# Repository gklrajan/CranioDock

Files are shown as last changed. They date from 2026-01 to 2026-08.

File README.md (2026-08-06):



# CranioDock: Open-Source 3D-Printable Mounts for Brain Imaging with Visual and Auditory stimulation in Danionella

**CranioDock** is an open-source, modular 3D-printed mounting system designed for brain imaging in adult *Danionella* fish (and other similar animal models). This setup provides stable head-fixation, precise alignment with visual/ auditory stimuli, and easy integration with upright microscopes with water immersion or dry objectives that have sufficient working distance.

This repository contains all the necessary STL and STEP files to fabricate and assemble the mounting system, along with notes on assembly and experimental usage.

---

## Parts

| Part Name | File Path |
|---|---|
| Inner fish holder (common) | `models/fish-holder_v2-m.STL` |
| Outer chamber (for visual stimulation) | `models/visualStim_intubation-chamber_v2.STL` |
| Outer chamber (for auditory stimulation)  | `models/auditoryStim_outer-chamber_complete-setup_v3.STEP`|

Tip 1: if you do not have an in-house 3D printing facility, I can recommend Protolabs Network (previously called 3D HUBS) - I've had a good experience with 3D HUBS in Europe.

---

## Assembly Guide

- This is the inner fish holder that secures the fish and it is common to both the outer chambers - visual and auditory. A cover slip is used to cover the exposed surface (for visual stimulation) at bottom of the holder.

  <div align="center">
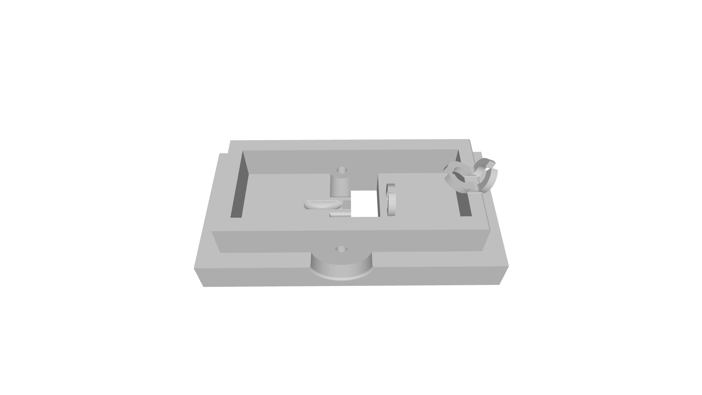
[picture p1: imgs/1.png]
fish-holder
    
  </div>

- This is the outer chamber for visual stimulation where the inner chamber fits in:

  <div align="center">
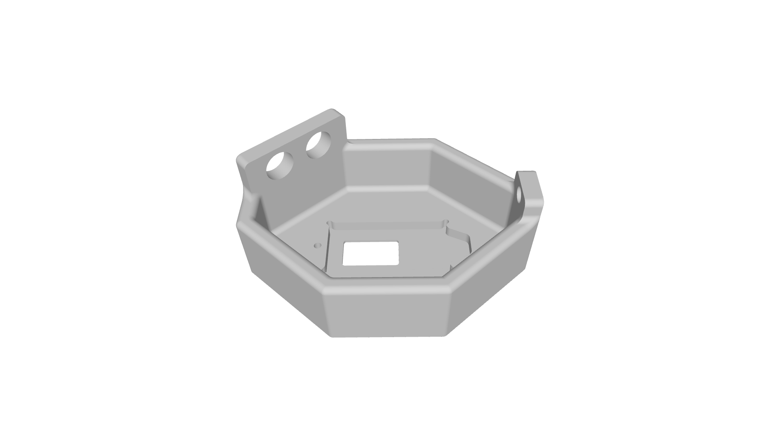
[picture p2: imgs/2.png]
vis-holder
    
  </div>

- For the outer visual stimulus chamber, an additional cover slip is needed to cover **A**. **B** is a space to attach a spring lock to hold the inner chamber in place. Only a food grade silicone sealant is used (Dow Corning 786) wherever sealing is necessary.

  <div align="center">
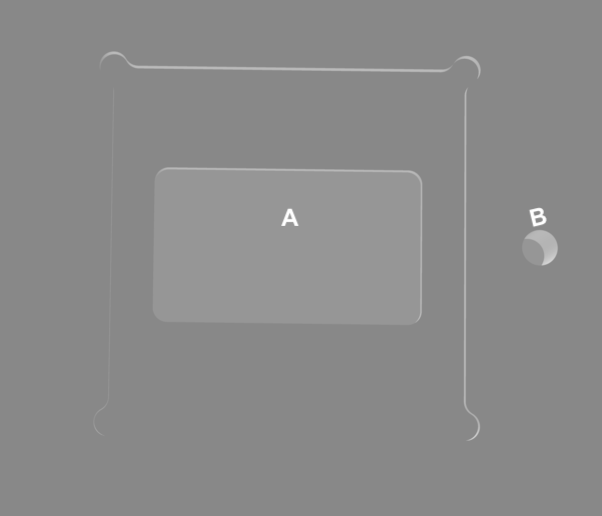
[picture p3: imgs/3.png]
cover-slip
    
  </div>

- The auditory stimulus chamber is as follows with a space for holding the underwater speaker and a stage for fitting the inner fish chamber with the fish facing the speaker. A small threaded hole is provided to lock the speaker in place when it is immersed in water.

  <div align="center">
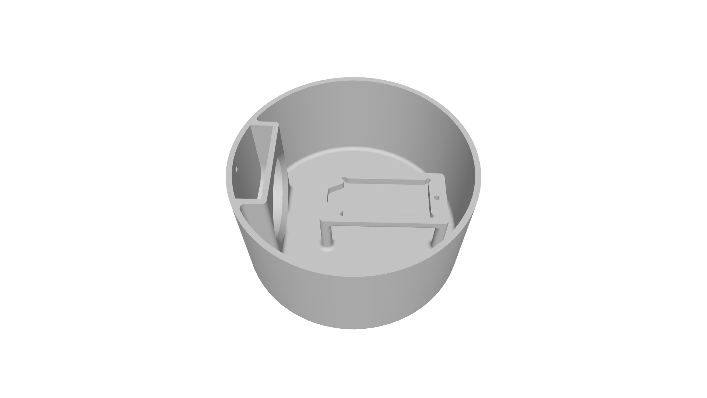
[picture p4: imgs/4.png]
aud-holder
    
  </div>

- An illustration of the complete auditory setup is below:

  <div align="center">
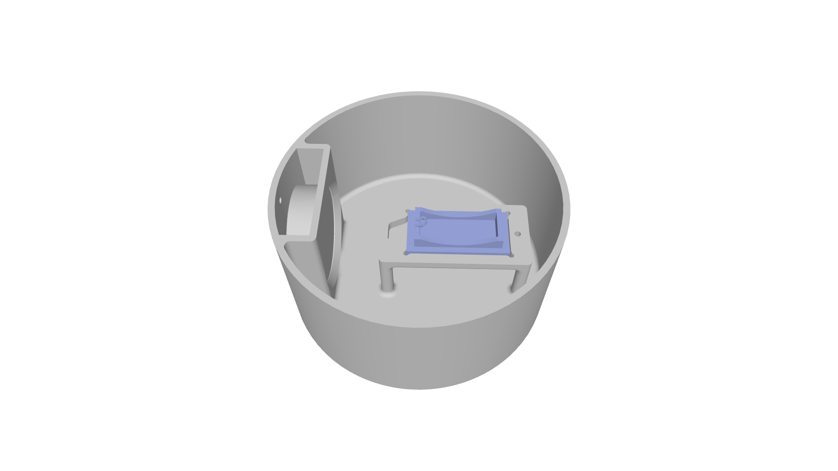
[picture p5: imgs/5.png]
    
  </div>

---

## Experimental Use

- Compatible with upright objectives. Designed for functional calcium imaging in *Danionella* (and other similar animal models) with visual and auditory stimulus delivery.
  
- Nylon screws displayed below (RS PRO M2 x 16.0mm Slotted Pan Head Screw, 0.40mm Thread Pitch, Nylon) are used to a) support the anesthetized fish to stay upright during mounting and b) protect the gills from agar.

    <div align="center">
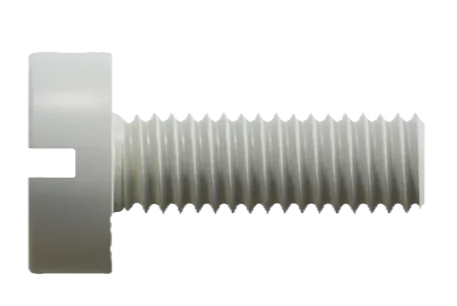
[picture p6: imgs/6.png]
nylon-screw
    
    </div>
    
- These screws are inserted from either side (positions C1 and C2) to support the anesthetized fish upright in the center:

    <div align="center">
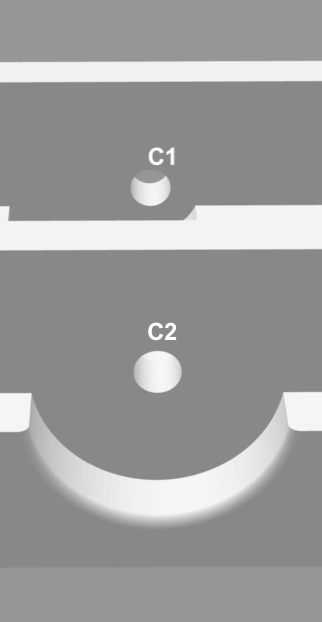
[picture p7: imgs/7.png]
support-screw
    
    </div>    

- Firstly, the fish is anesthetized before transferring them to the inner fish holder for mounting. Once moved to the fish chamber, it is positioned between the two screws covering the gills and the water is removed before application of 2.5% agar.

- The trunk of the fish (behind the screws covering the gills) is now completely immersed in 2.5% agar and a few drops of the agar is added in the anterior part of the mount - between the fish head and the gap left for the visual stimulation screen. Once agar is settled, remove the nylon screws and clear any remnants of agar around the gills and also around the mouth.

- After this, the tricaine anesthetic is washed off and the fish embedded in the holder is transferred to the appropriate outer chamber for brain imaging.

- Intubation-compatible: chamber slots accommodate tubings for perfussion of fish system water. The inflow is gravity-based using a simple over-the-counter saline container and an IV administration set. The system water is continuously drained out using 6VDC/ 5W peristaltic pump set at a constant height in the imaging chamber.

    <div align="center">
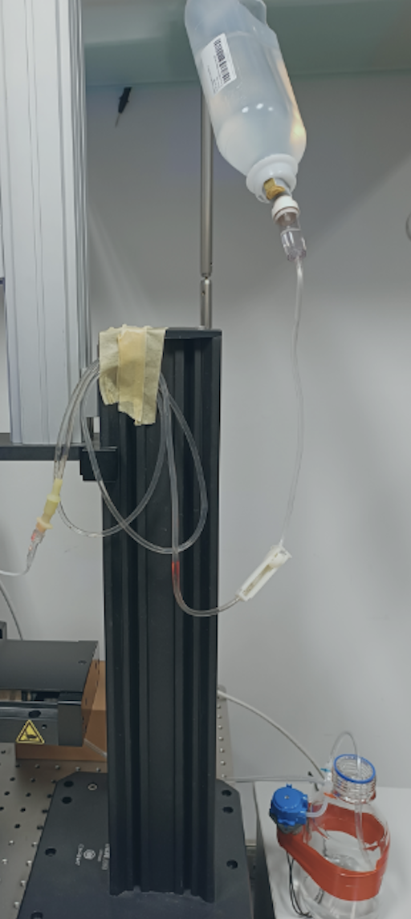
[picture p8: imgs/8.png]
perfussion
    
    </div>

- For long-term imaging studies, the prep can benefit from oxygenation and temperature control, which were not implemented in our current system where acquistions lasted for short time intervals where fresh system water maintained at room temperature was continuously provided.

Tip 2: freeing too much of the gills and/or mouth will cause a lot of motion artifacts. This step is critical for good imaging and needs to be done carefully.

Tip 3: the mount is used on ~4 to 12 months old adult (male) fish. The younger adults (~2 months or so) can be significantly smaller in size and still growing. If using on such a stage of the fish, the size of the nylon screw used in the mount needs to be adjusted accordingly.

---

## License

This project is shared under the [Creative Commons Attribution 4.0 International License (CC BY 4.0)](https://creativecommons.org/licenses/by/4.0/).

---

## Author

Developed by Gokul Rajan. Orger Lab, Champalimaud Foundation.

---

## Citation

Gokul Rajan. (2026). CranioDock: Open-Source 3D-Printable Mounts for Brain Imaging with Visual and Auditory stimulation in Danionella (v1.0.0). Zenodo. https://doi.org/10.5281/zenodo.18178642

---

## Acknowledgement

This project was developed at the Champalimaud Foundation (CF) in the Vision to Action Laboratory of Michael B. Orger. Thanks to the Hardware Platform (especially Filipe Mendes) for translating my design into CAD models and fabricating the parts. Thanks also to Lucas Martins for creating a CAD model of an early version of my design. All of their advice was very much appreciated.

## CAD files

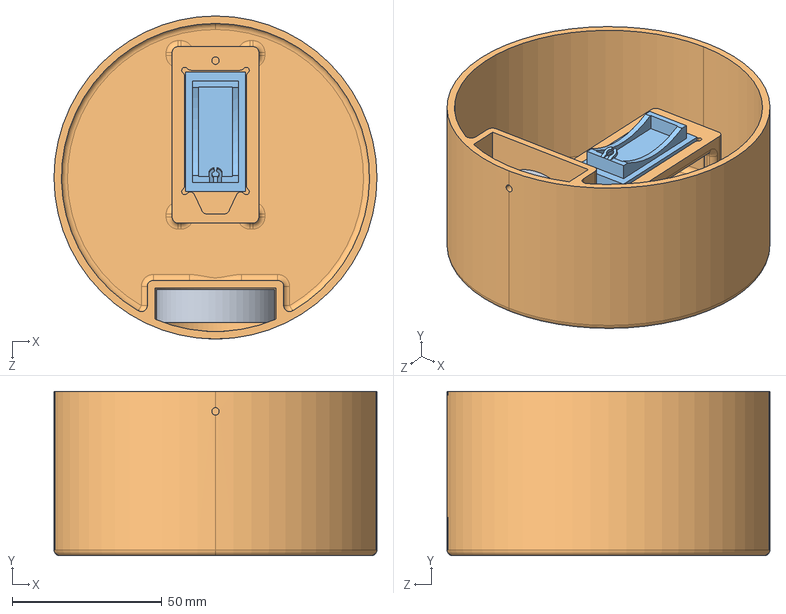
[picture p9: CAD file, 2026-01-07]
models/auditoryStim_outer-chamber_complete-setup_v3.STEP
108.0 x 55.0 x 108.0 mm
Speaker_chamber_v1
fish holder_v3

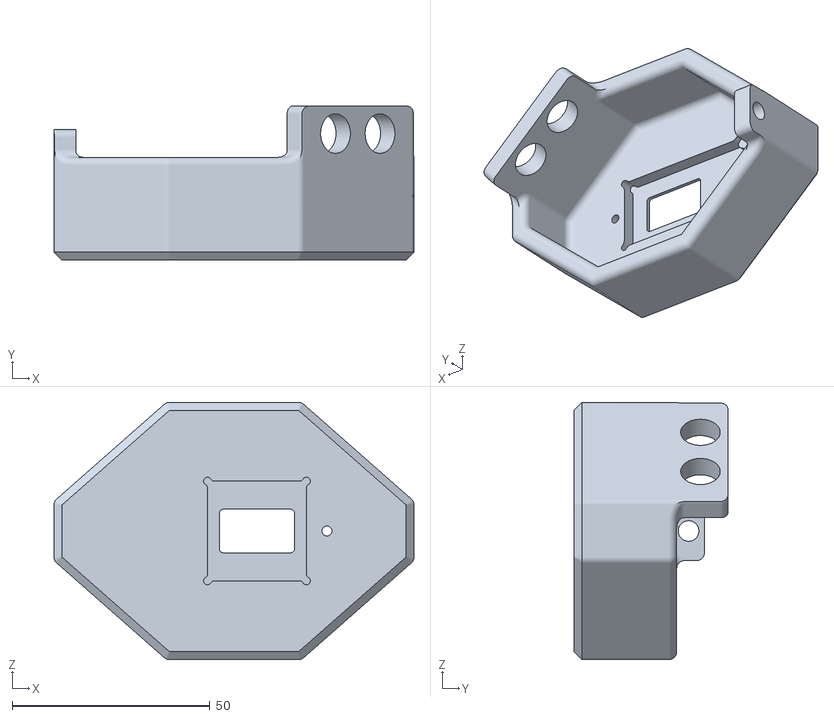
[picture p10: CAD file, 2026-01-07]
models/visualStim_intubation-chamber_v2.STL
91.0 x 39.0 x 65.0

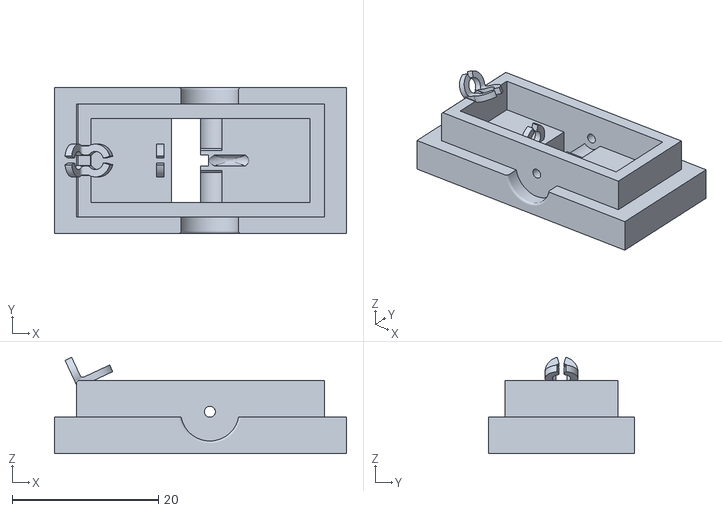
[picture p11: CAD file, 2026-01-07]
models/fish-holder_v2-m.STL
40.0 x 20.0 x 13.2
